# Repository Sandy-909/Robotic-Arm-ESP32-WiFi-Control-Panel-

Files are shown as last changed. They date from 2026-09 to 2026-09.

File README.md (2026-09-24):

# Robotic-Arm-ESP32-WiFi-Control-Panel-
An open-source, 3D-printed robotic arm controlled wirelessly over WiFi from a browser-based control panel — no app install, no cables, no COM port required. Built from scratch: CAD → 3D printing → embedded firmware → custom web UI. Fully assembled, wired, and working.

ROBOTIC_ARM

Overview

This project is a 5-axis robotic arm (Base, Shoulder, Elbow, Wrist Pitch, Wrist Roll, plus a Gripper) driven by an ESP32 microcontroller. The ESP32 hosts its own WiFi access point and serves a full control panel directly from the board — open the arm's IP address in any browser, no separate files, no app, no COM port. Every joint is controlled with a slider, with live angle readout, smooth per-joint speed-ramped movement, saved pose sequences, playback, and export/import.

All mechanical parts are 3D printed. All code — firmware and control panel — is included in this repo.

Features
6-channel servo control (5 arm joints + gripper)
Self-hosted browser control panel — served directly from the ESP32, just open its IP address
Live slider control per joint with real-time angle display
Smooth, per-joint speed-ramped movement — each joint moves in small steps rather than snapping instantly, with independently tunable speed per joint (heavier MG995 joints vs. lighter SG90 joints move differently)
Save Position — capture the current pose
Play Movements — play back saved poses in sequence with adjustable delay
Stop Movement — halt playback mid-sequence
Export / Import Positions — save and reload movement sequences as .json files
Reset Positions — return all joints to a safe default pose
No app installation — runs in any modern browser

## Hardware / Bill of Materials

| Component | Qty | Notes |
|---|---:|---|
| ESP32 Dev Board (NodeMCU-32S) | 1 | 5V input via onboard 5V/VIN pin |
| MG995 Servo (Positional, 180°) | 3 | Base, Shoulder, and Elbow joints |
| SG90 Servo | 3 | Wrist Pitch, Wrist Roll, and Gripper |
| 5V Input Power Supply (3A+) | 1 | Use a power adapter of 5V 3A  |
| DC Barrel Jack | 1 | Center-positive (tip = +, sleeve = −) |
| 3D Printed Parts | — | See `/cad` folder for STL and source files |
| M3 Screws & nuts | as required  | See CAD assembly  |
| Jumper Wires | — | Used for signal and power distribution |
⚠️ Important: Make sure any MG995 you buy is listed as 180° positional, not "continuous rotation" or "for robot wheels" — these look identical but behave completely differently. See Lessons Learned below.

### Wiring

circuit_image

## General Wiring Notes

- **Servo Signal:** Connect each servo's signal wire to a dedicated GPIO pin on the ESP32. See `SERVO_PINS[]` in the firmware and update the pin assignments to match your actual wiring.

- **Servo Power:** All servo V+ connections must come directly from the external buck converter's **5V rail**. Do **not** power the servos from the ESP32's onboard regulator.

- **ESP32 Power:** For untethered operation, power the ESP32 from the **same 5V/GND rail** as the servos through the board's **5V/VIN and GND pins**. Do not rely on USB power during normal operation.

- **Common Ground:** This is critical. Connect:
  - ESP32 GND
  - Power adapter GND
  - All servo GND wires
  
  These must share a common ground. Without a common reference, the PWM signals can become unstable and cause erratic or uncontrolled servo movement.

- **DC Barrel Jack:** Before soldering, use a multimeter in continuity mode to verify:
  - Tip = Positive (+)
  - Sleeve = Negative (−)
  
  Do not assume the pin arrangement. Some barrel jacks have a third **switch/detect pin** that can look like a power connection.

- **Perfboard / Prototyping Board:** Carefully inspect every solder joint along the power path. A cold or weak solder joint may show the correct voltage with a multimeter but still cause voltage drops during sudden current bursts, especially when the ESP32's Wi-Fi starts broadcasting.

## Software Setup

### Firmware (ESP32)

The firmware is located in the `/firmware` folder:

`robotic_arm_wifi_control_panel.ino`

This single file contains both the **Wi-Fi server** and the complete **web-based control panel** for the robotic arm.

### Requirements

- [Arduino IDE](https://www.arduino.cc/en/software) with **ESP32 board support** installed.
- **ESP32Servo** library by **Kevin Harrington**.
  - Install it through the Arduino IDE **Library Manager**.

## Setup & Upload

**Steps:**
1. Open `robotic_arm_wifi_control_panel.ino` in the **Arduino IDE**.
2. Update `SERVO_PINS[]` and `JOINT_NAMES[]` to match your actual wiring.
3. Tune the movement speed for each joint if required:
   - `STEP_SIZE[]` — degrees moved per step.
   - `STEP_INTERVAL_MS[]` — delay in milliseconds between steps.
   - Use one value for each joint.
   - Heavier **MG995** joints generally work better with smaller/slower steps, while lighter **SG90** joints can use faster movement.
4. *(Optional)* Change `WIFI_SSID` and `WIFI_PASSWORD` if required.
5. Connect the ESP32 and **upload the firmware**.
6. Open the **Serial Monitor** at `115200` baud.
7. Check the Serial Monitor for the arm's IP address. The default access point address is:
   ```text
   192.168.4.1

### Control Panel

No separate file or installation is required. The **ESP32 hosts and serves the control panel directly**.

**Steps:**

1. Power on the robotic arm.
2. On your phone or laptop, connect to the **ESP32 Wi-Fi network**. The SSID is shown in the Serial Monitor.
3. Open a web browser and enter the arm's IP address, for example:
   ```text
   http://192.168.4.1

### Contributing

Issues and pull requests are welcome. If you build this arm yourself, feel free to open an issue with photos — always good to see other builds.

### License

This project is licensed under the MIT License — free to use, modify, and distribute.

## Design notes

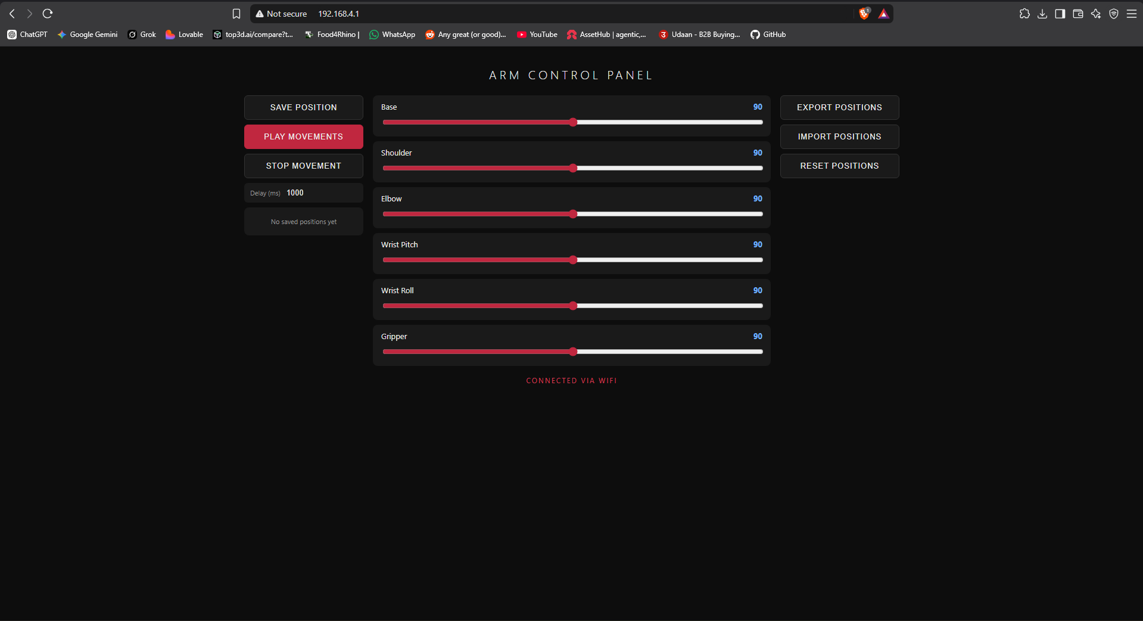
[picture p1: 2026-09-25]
firmware/GUI_PREVIEW.png

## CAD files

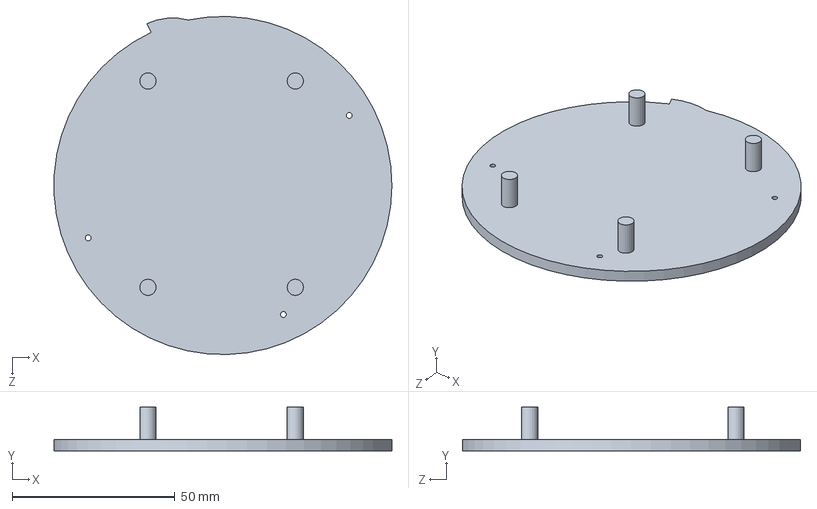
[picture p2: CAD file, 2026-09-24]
CAD/base_bottom cap.SLDPRT
103.9 x 13.5 x 104.0 mm

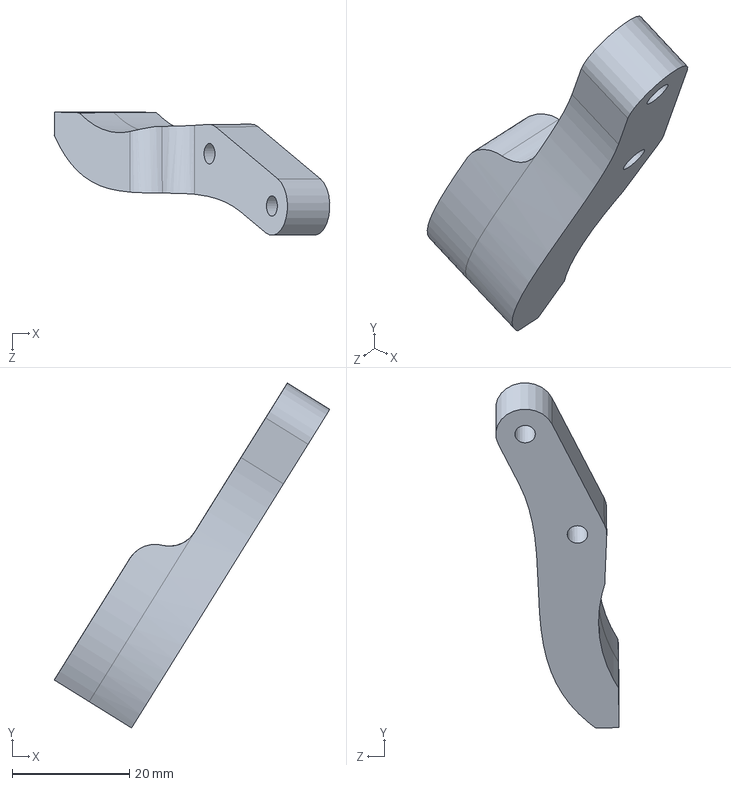
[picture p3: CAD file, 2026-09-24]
CAD/claw_hand_2.SLDPRT
46.9 x 58.8 x 21.0 mm

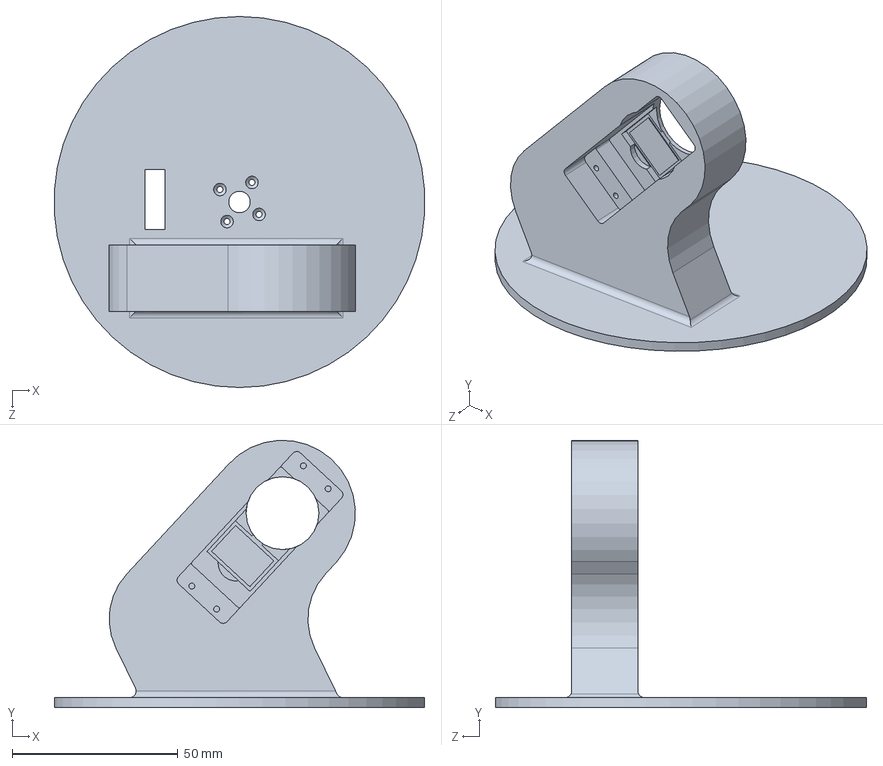
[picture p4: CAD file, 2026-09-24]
CAD/Link_1.SLDPRT
111.8 x 80.7 x 112.0 mm

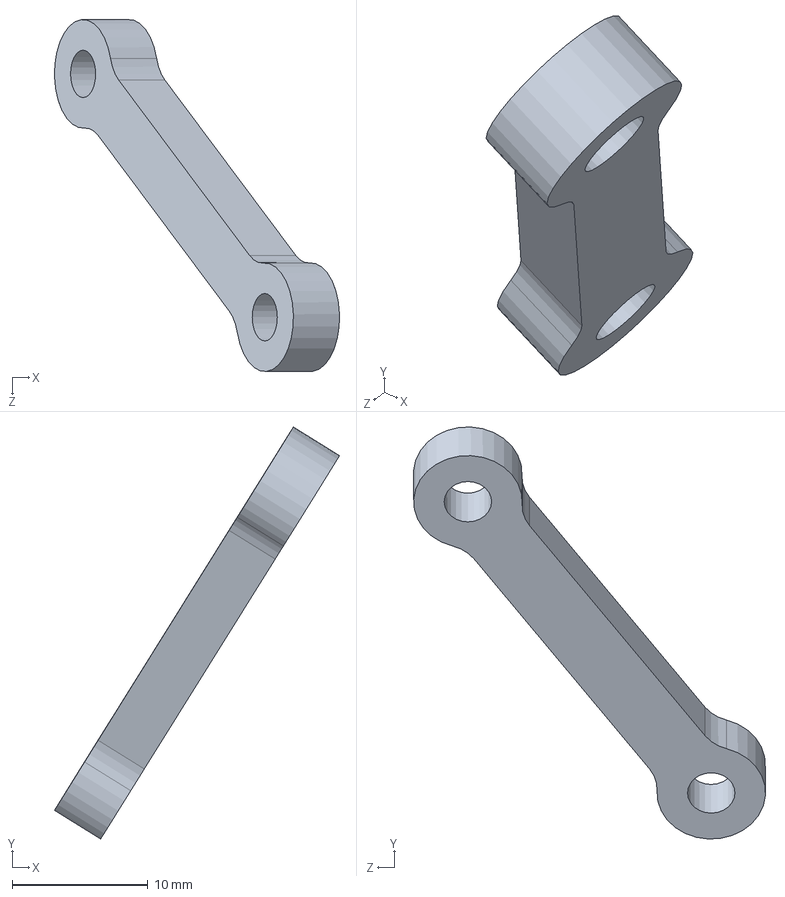
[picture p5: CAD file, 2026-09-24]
CAD/gear_link.SLDPRT
21.0 x 30.4 x 25.9 mm

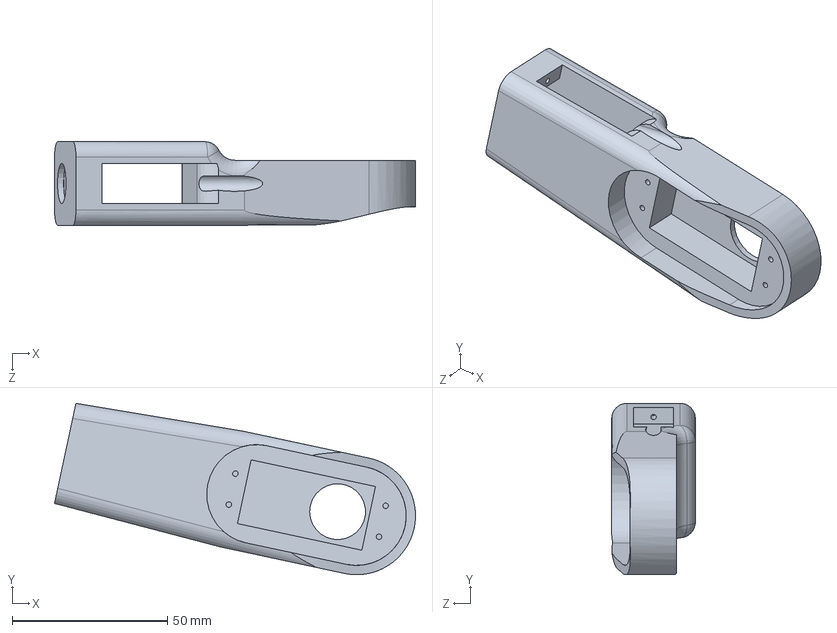
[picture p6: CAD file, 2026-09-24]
CAD/link_fix2.SLDPRT
116.3 x 55.2 x 27.0 mm

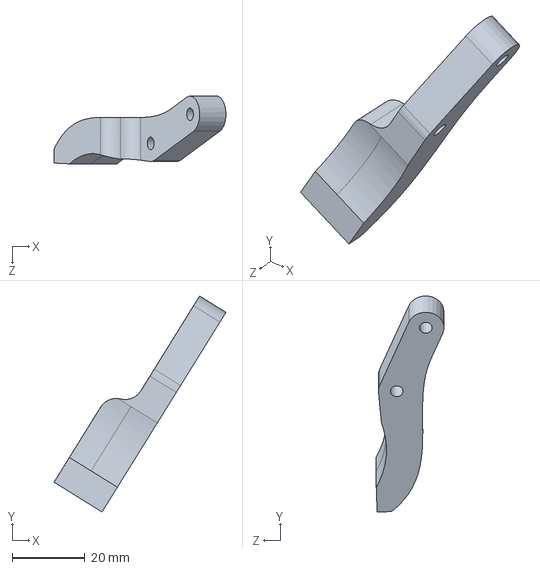
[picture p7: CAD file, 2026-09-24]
CAD/claw_hand.SLDPRT
47.2 x 59.3 x 18.6 mm

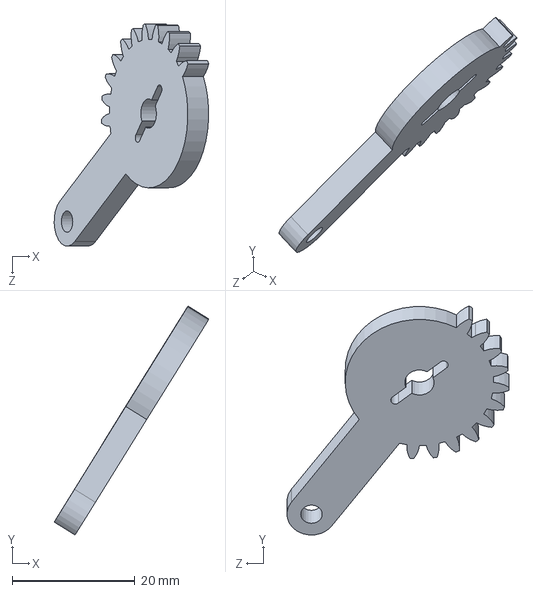
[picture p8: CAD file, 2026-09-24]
CAD/claw_gear2new.SLDPRT
25.2 x 37.3 x 36.2 mm

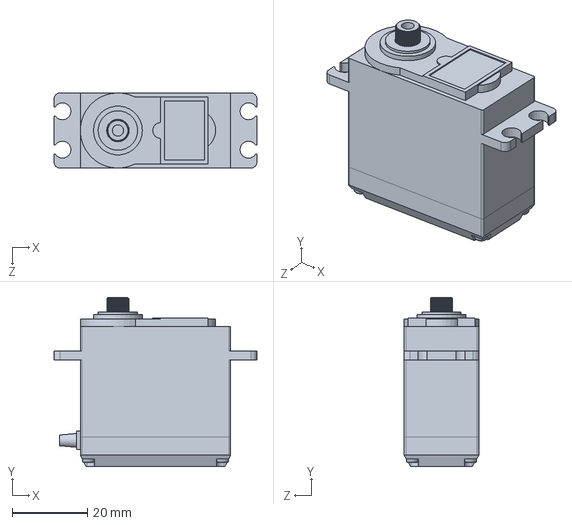
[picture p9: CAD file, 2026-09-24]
CAD/MG995.o11k.SLDPRT
54.0 x 45.0 x 20.0 mm

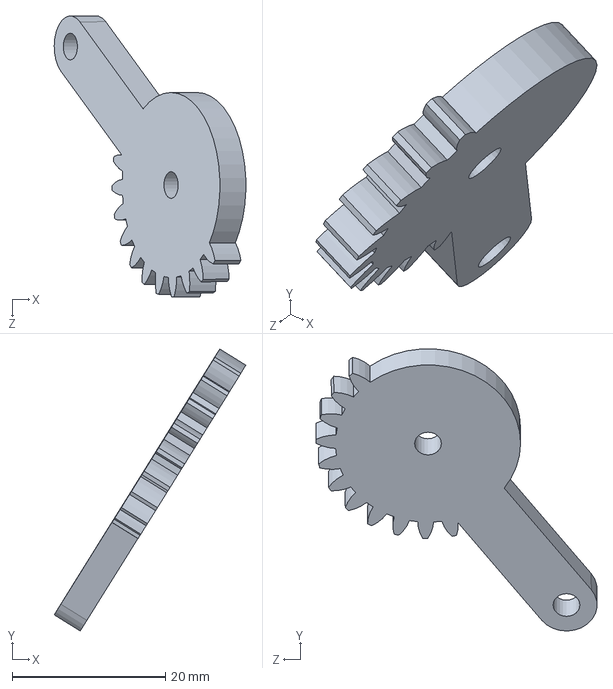
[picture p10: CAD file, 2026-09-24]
CAD/claw_gea1.SLDPRT
25.0 x 36.8 x 36.7 mm

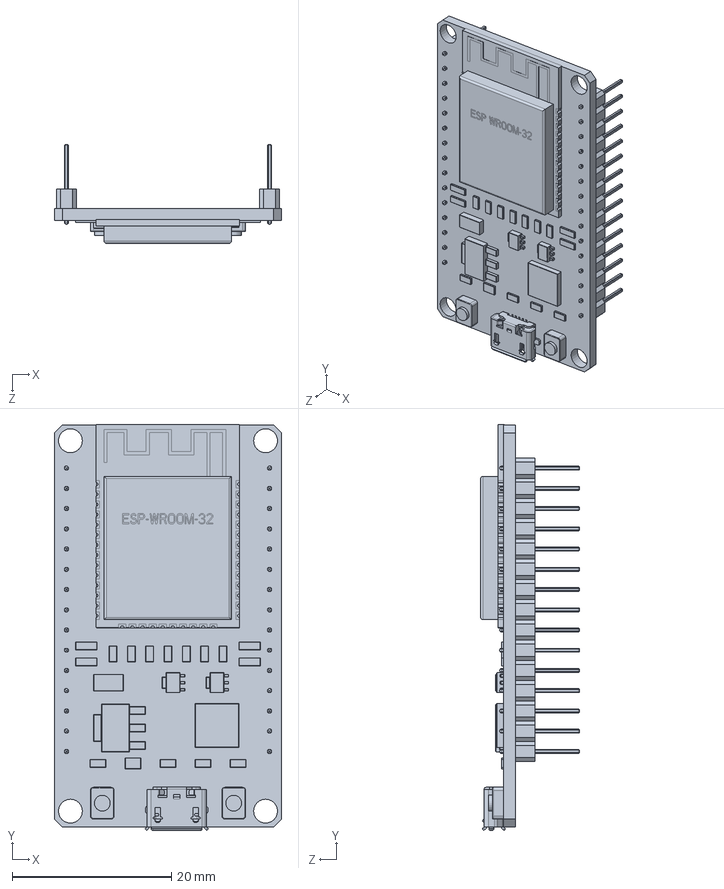
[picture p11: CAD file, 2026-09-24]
CAD/ESP-32.SLDPRT
28.5 x 51.0 x 12.4 mm

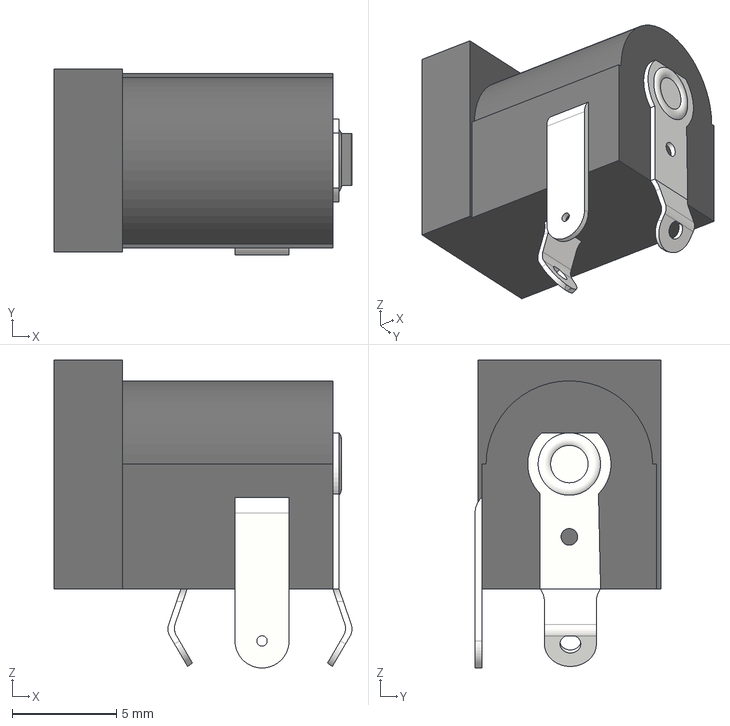
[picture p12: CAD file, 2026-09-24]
CAD/dc jack with legs.step
14.3 x 8.93 x 14.8 mm

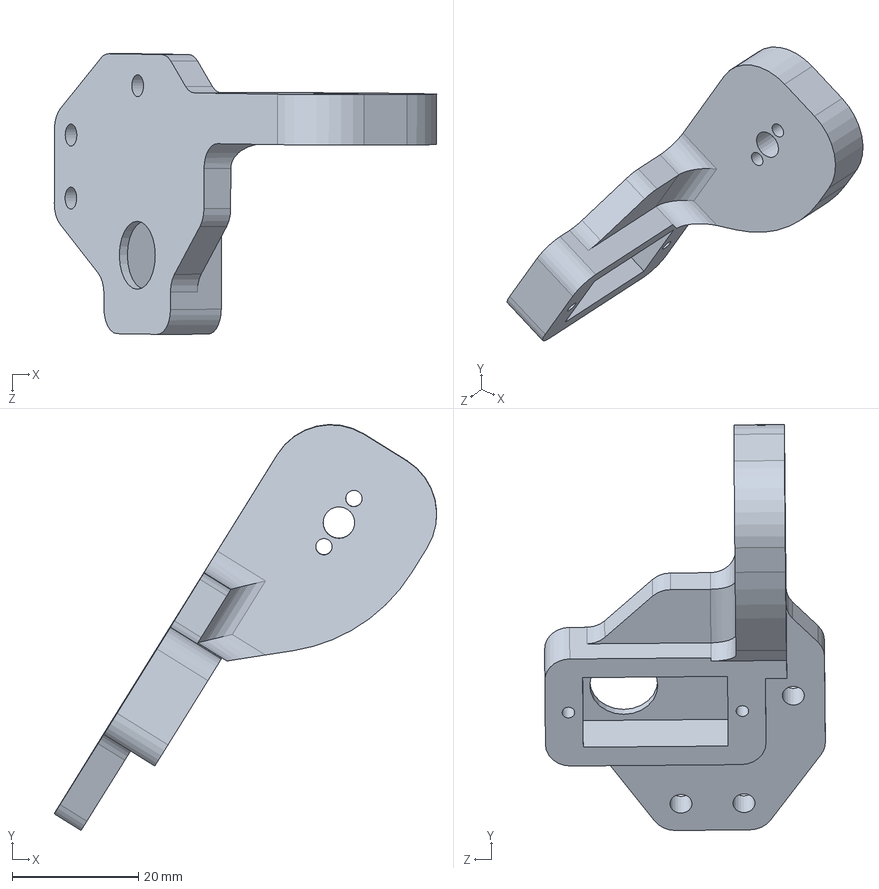
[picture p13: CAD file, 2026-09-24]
CAD/claw_1.SLDPRT
60.7 x 64.4 x 44.5 mm

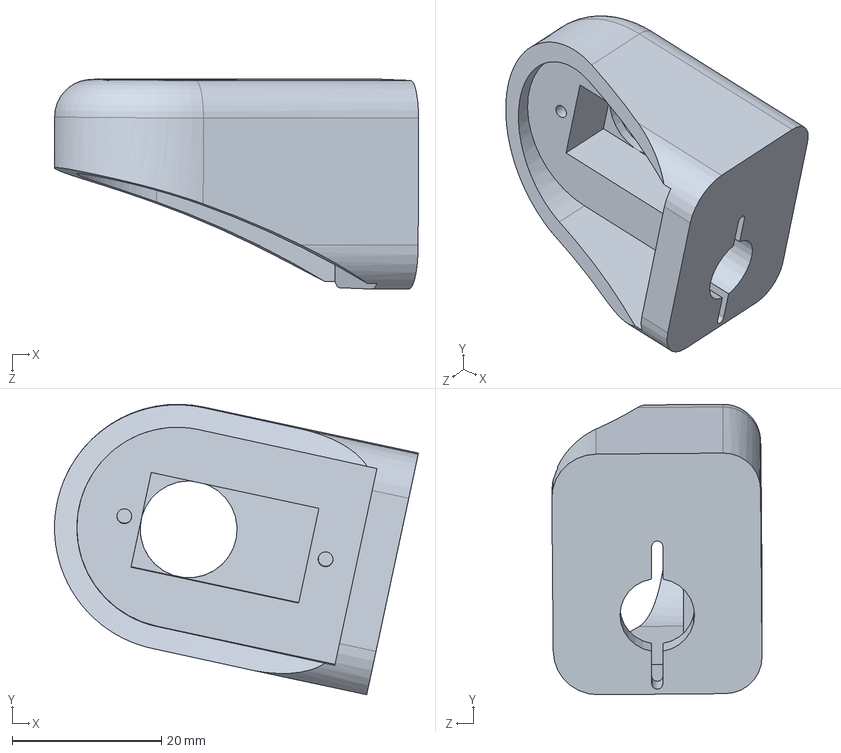
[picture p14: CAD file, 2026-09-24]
CAD/link_3.SLDPRT
48.8 x 39.0 x 28.2 mm

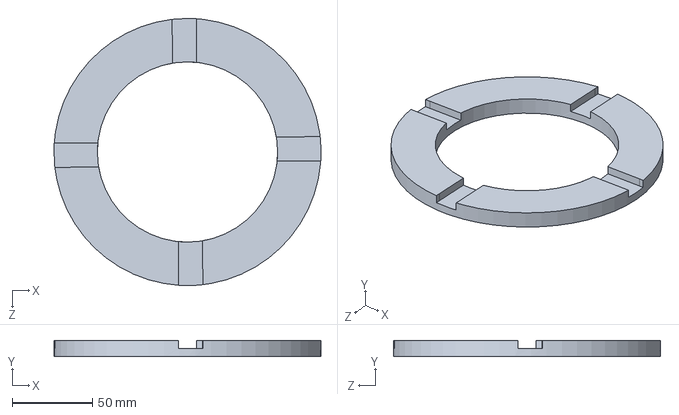
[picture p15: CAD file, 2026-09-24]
CAD/base_support.SLDPRT
165.9 x 10.0 x 166.0 mm

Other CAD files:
CAD/Assem1.SLDASM
CAD/MG995.step
CAD/link_2_new.SLDPRT
CAD/servo90s.SLDPRT
CAD/MG955 horn.SLDPRT
CAD/MG995.SLDASM
CAD/MG995.SLDPRT
CAD/Power jack.SLDPRT
CAD/base.SLDPRT

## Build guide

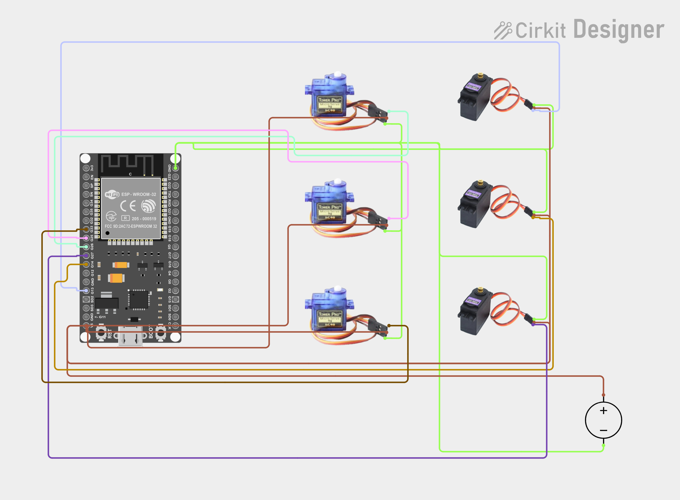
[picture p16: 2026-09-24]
wiring diagram/circuit_image.png

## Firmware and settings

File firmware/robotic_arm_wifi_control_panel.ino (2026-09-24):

/*
  6-Axis Robotic Arm - WiFi Web Control Panel - ESP32
  -------------------------------------------------------------------------
  ESP32 hosts its OWN WiFi network (Access Point mode). Connect your
  phone/laptop to that network, open the IP in a browser, and you get
  a full control panel: sliders, Save Position, Play Movements, Stop,
  Export/Import Positions (as a file), and Reset -- all running purely
  over WiFi, no USB/serial connection needed once it's powered on.

  WIRING:
    Update SERVO_PINS[] below to match your actual joint -> GPIO wiring.
    Label each joint in JOINT_NAMES[] to match your arm (Base, Shoulder, etc).
    All servos need a separate 5-6V supply (2A+ per servo) with GND
    common to the ESP32.

  SETUP:
    1. Install "ESP32Servo" library (Kevin Harrington) via Library Manager.
    2. Change WIFI_SSID / WIFI_PASSWORD below if you want.
    3. Upload, open Serial Monitor at 115200 to see the IP address.
    4. On your phone/laptop, join the WiFi network shown, then open that
       IP in any browser (e.g. http://192.168.4.1).
*/

#include <WiFi.h>
#include <WebServer.h>
#include <ESP32Servo.h>

// ---------- CONFIG: EDIT THESE FOR YOUR ARM ----------
const int SERVO_PINS[6]     = {13, 14, 27, 26, 25, 33};
const char* JOINT_NAMES[6]  = {"Base", "Shoulder", "Elbow", "Wrist Pitch", "Wrist Roll", "Gripper"};
const int DEFAULT_ANGLE[6]  = {90, 90, 90, 90, 90, 90};

const char* WIFI_SSID     = "RoboticArm";
const char* WIFI_PASSWORD = "arm12345";   // must be 8+ characters

// ---------- SPEED CONTROL (per joint) ----------
// Lower STEP_SIZE and/or higher STEP_INTERVAL_MS = slower, smoother movement.
// Higher STEP_SIZE and/or lower STEP_INTERVAL_MS = faster movement.
// Set one value per joint, in the same order as SERVO_PINS/JOINT_NAMES above.
// Example below: Base/Shoulder/Elbow are MG995 (slower, more torque),
// Wrist Pitch/Wrist Roll/Gripper are SG90 (faster, confirmed working at 2 steps / 30ms).
const int STEP_SIZE[6]         = {1,  1,  1,  2,  2,  2};   // degrees moved per step
const int STEP_INTERVAL_MS[6]  = {15, 15, 15, 30, 30, 30};  // milliseconds between steps
// ------------------------------------------------------

Servo joints[6];
int currentAngle[6];   // angle the servo is actually at right now
int targetAngle[6];    // angle we're ramping toward
unsigned long lastStepTime[6];  // tracked per servo since speeds now differ
WebServer server(80);

void handleRoot() {
  String html = "<!DOCTYPE html><html><head><meta charset='utf-8'>";
  html += "<meta name='viewport' content='width=device-width, initial-scale=1'>";
  html += "<title>Arm Control Panel</title><style>";
  html += ":root{--bg:#0d0d0d;--panel:#1a1a1a;--accent:#c0273f;--accent-hover:#d63a53;--text:#eee;--muted:#999;}";
  html += "*{box-sizing:border-box;}";
  html += "body{background:var(--bg);color:var(--text);font-family:'Segoe UI',Arial,sans-serif;margin:0;padding:20px;}";
  html += "h1{text-align:center;font-weight:300;letter-spacing:5px;font-size:20px;margin-bottom:22px;text-transform:uppercase;}";
  html += ".layout{display:flex;gap:16px;max-width:1100px;margin:0 auto;flex-wrap:wrap;}";
  html += ".col{display:flex;flex-direction:column;gap:8px;}";
  html += ".col-side{width:200px;}";
  html += ".col-main{flex:1;min-width:280px;}";
  html += "button,select{background:var(--panel);color:var(--text);border:1px solid #333;border-radius:6px;padding:12px 10px;font-size:13px;letter-spacing:1px;cursor:pointer;text-transform:uppercase;width:100%;}";
  html += "button:hover{background:#262626;}";
  html += "button:disabled{opacity:0.4;cursor:not-allowed;}";
  html += ".primary{background:var(--accent);border-color:var(--accent);}";
  html += ".primary:hover{background:var(--accent-hover);}";
  html += ".primary.playing{background:var(--accent-hover);}";
  html += ".joint{background:var(--panel);border-radius:8px;padding:10px 14px;}";
  html += ".joint-label{display:flex;justify-content:space-between;font-size:13px;margin-bottom:6px;}";
  html += ".joint-label .val{color:#6fb3ff;font-weight:bold;}";
  html += "input[type=range]{width:100%;accent-color:var(--accent);height:20px;}";
  html += ".delay-box{display:flex;align-items:center;background:var(--panel);border-radius:6px;padding:8px 10px;gap:8px;}";
  html += ".delay-box input{background:transparent;border:none;color:var(--text);width:100%;font-size:13px;}";
  html += ".delay-box label{font-size:11px;color:var(--muted);white-space:nowrap;}";
  html += ".status{text-align:center;margin-top:16px;font-size:12px;letter-spacing:2px;color:var(--muted);text-transform:uppercase;}";
  html += ".status.active{color:var(--accent-hover);}";
  html += ".saved-list{background:var(--panel);border-radius:8px;padding:8px 12px;max-height:150px;overflow-y:auto;font-size:12px;}";
  html += ".pose-row{display:flex;justify-content:space-between;align-items:center;padding:5px 0;border-bottom:1px solid #262626;}";
  html += ".pose-row:last-child{border-bottom:none;}";
  html += ".pose-row button{width:auto;padding:3px 7px;font-size:10px;}";
  html += ".empty-note{color:var(--muted);font-size:11px;text-align:center;padding:8px 0;}";
  html += "#importFile{display:none;}";
  html += "</style></head><body>";
  html += "<h1>Arm Control Panel</h1><div class='layout'>";

  // Left column
  html += "<div class='col col-side'>";
  html += "<button id='saveBtn'>Save Position</button>";
  html += "<button id='playBtn' class='primary'>Play Movements</button>";
  html += "<button id='stopBtn'>Stop Movement</button>";
  html += "<div class='delay-box'><label>Delay (ms)</label><input type='number' id='delayInput' value='1000' min='50' step='50'></div>";
  html += "<div class='saved-list' id='savedList'><div class='empty-note'>No saved positions yet</div></div>";
  html += "</div>";

  // Middle column: sliders
  html += "<div class='col col-main' id='jointContainer'>";
  for (int i = 0; i < 6; i++) {
    html += "<div class='joint'>";
    html += "<div class='joint-label'><span>" + String(JOINT_NAMES[i]) + "</span><span class='val' id='v" + i + "'>" + String(currentAngle[i]) + "</span></div>";
    html += "<input type='range' min='0' max='180' value='" + String(currentAngle[i]) + "' id='s" + i + "' oninput='onSlide(" + String(i) + ",this.value)'>";
    html += "</div>";
  }
  html += "</div>";

  // Right column
  html += "<div class='col col-side'>";
  html += "<button id='exportBtn'>Export Positions</button>";
  html += "<button id='importBtn'>Import Positions</button>";
  html += "<input type='file' id='importFile' accept='application/json'>";
  html += "<button id='resetBtn'>Reset Positions</button>";
  html += "</div>";

  html += "</div><div class='status active' id='statusLine'>Connected via WiFi</div>";

  // JS
  html += "<script>";
  html += "let angles=[" ;
  for (int i = 0; i < 6; i++) { html += String(currentAngle[i]); if (i < 5) html += ","; }
  html += "];";
  html += "let savedPoses=[];let playing=false;let stopRequested=false;";
  html += "const playBtn=document.getElementById('playBtn');const statusLine=document.getElementById('statusLine');const savedList=document.getElementById('savedList');";

  html += "function setStatus(t,a){statusLine.innerText=t;statusLine.classList.toggle('active',!!a);}";

  html += "function onSlide(i,v){angles[i]=parseInt(v);document.getElementById('v'+i).innerText=v;sendAngles();}";

  html += "function updateSliders(){angles.forEach((a,i)=>{document.getElementById('s'+i).value=a;document.getElementById('v'+i).innerText=a;});}";

  html += "async function sendAngles(){";
  html += "let url='/moveAll?';";
  html += "angles.forEach((a,i)=>{url+='a'+i+'='+a+'&';});";
  html += "try{await fetch(url);}catch(e){setStatus('Send failed -- check WiFi connection');}";
  html += "}";

  html += "function renderSavedList(){";
  html += "if(savedPoses.length===0){savedList.innerHTML='<div class=\"empty-note\">No saved positions yet</div>';return;}";
  html += "savedList.innerHTML='';";
  html += "savedPoses.forEach((pose,idx)=>{";
  html += "const row=document.createElement('div');row.className='pose-row';";
  html += "row.innerHTML='<span>Pose '+(idx+1)+': '+pose.join(', ')+'</span>';";
  html += "const delBtn=document.createElement('button');delBtn.innerText='X';";
  html += "delBtn.onclick=()=>{savedPoses.splice(idx,1);renderSavedList();};";
  html += "row.appendChild(delBtn);savedList.appendChild(row);";
  html += "});}";

  html += "function sleep(ms){return new Promise(r=>setTimeout(r,ms));}";

  html += "document.getElementById('saveBtn').addEventListener('click',()=>{savedPoses.push([...angles]);renderSavedList();});";

  html += "document.getElementById('playBtn').addEventListener('click',async()=>{";
  html += "if(playing)return;";
  html += "if(savedPoses.length===0){setStatus('No saved positions to play');return;}";
  html += "playing=true;stopRequested=false;playBtn.classList.add('playing');";
  html += "const delayMs=parseInt(document.getElementById('delayInput').value)||1000;";
  html += "for(let i=0;i<savedPoses.length;i++){";
  html += "if(stopRequested)break;";
  html += "angles=[...savedPoses[i]];updateSliders();await sendAngles();";
  html += "setStatus('Playing movement '+(i+1)+' of '+savedPoses.length,true);";
  html += "await sleep(delayMs);}";
  html += "playing=false;playBtn.classList.remove('playing');";
  html += "setStatus(stopRequested?'Stopped':'Playback finished',true);";
  html += "});";

  html += "document.getElementById('stopBtn').addEventListener('click',()=>{stopRequested=true;setStatus('Stopping...');});";

  html += "document.getElementById('exportBtn').addEventListener('click',()=>{";
  html += "const blob=new Blob([JSON.stringify(savedPoses,null,2)],{type:'application/json'});";
  html += "const url=URL.createObjectURL(blob);const a=document.createElement('a');";
  html += "a.href=url;a.download='arm_positions.json';a.click();URL.revokeObjectURL(url);";
  html += "});";

  html += "document.getElementById('importBtn').addEventListener('click',()=>{document.getElementById('importFile').click();});";

  html += "document.getElementById('importFile').addEventListener('change',(e)=>{";
  html += "const file=e.target.files[0];if(!file)return;";
  html += "const r=new FileReader();";
  html += "r.onload=(evt)=>{try{const data=JSON.parse(evt.target.result);if(Array.isArray(data)){savedPoses=data;renderSavedList();setStatus('Positions imported',true);}}catch(err){setStatus('Invalid file');}};";
  html += "r.readAsText(file);";
  html += "});";

  html += "document.getElementById('resetBtn').addEventListener('click',()=>{";
  html += "angles=[" ;
  for (int i = 0; i < 6; i++) { html += String(DEFAULT_ANGLE[i]); if (i < 5) html += ","; }
  html += "];updateSliders();sendAngles();";
  html += "});";

  html += "</script></body></html>";

  server.send(200, "text/html", html);
}

void handleMoveAll() {
  for (int i = 0; i < 6; i++) {
    String param = "a" + String(i);
    if (server.hasArg(param)) {
      int angle = constrain(server.arg(param).toInt(), 0, 180);
      targetAngle[i] = angle;   // servo will ramp toward this in loop(), not jump instantly
    }
  }
  server.send(200, "text/plain", "OK");
}

// Moves each servo one small step closer to its target, at a fixed interval.
// This runs continuously in loop() so movement is smooth and non-blocking --
// the web page stays responsive while servos are still ramping.
void updateServoPositions() {
  unsigned long now = millis();
  for (int i = 0; i < 6; i++) {
    if (now - lastStepTime[i] < STEP_INTERVAL_MS[i]) continue;
    if (currentAngle[i] == targetAngle[i]) continue;

    lastStepTime[i] = now;
    if (currentAngle[i] < targetAngle[i]) {
      currentAngle[i] = min(currentAngle[i] + STEP_SIZE[i], targetAngle[i]);
    } else {
      currentAngle[i] = max(currentAngle[i] - STEP_SIZE[i], targetAngle[i]);
    }
    joints[i].write(currentAngle[i]);
  }
}

void setup() {
  Serial.begin(115200);
  delay(500);

  ESP32PWM::allocateTimer(0);
  ESP32PWM::allocateTimer(1);
  ESP32PWM::allocateTimer(2);
  ESP32PWM::allocateTimer(3);

  for (int i = 0; i < 6; i++) {
    joints[i].setPeriodHertz(50);
    joints[i].attach(SERVO_PINS[i], 500, 2400);
    currentAngle[i] = DEFAULT_ANGLE[i];
    targetAngle[i] = DEFAULT_ANGLE[i];
    joints[i].write(currentAngle[i]);
  }

  WiFi.softAP(WIFI_SSID, WIFI_PASSWORD);
  IPAddress ip = WiFi.softAPIP();

  Serial.println("=======================================");
  Serial.println(" Robotic Arm Web Control Panel Ready");
  Serial.println("=======================================");
  Serial.print("Connect to WiFi: ");
  Serial.println(WIFI_SSID);
  Serial.print("Password: ");
  Serial.println(WIFI_PASSWORD);
  Serial.print("Then open in browser: http://");
  Serial.println(ip);

  server.on("/", handleRoot);
  server.on("/moveAll", handleMoveAll);
  server.begin();
}

void loop() {
  server.handleClient();
  updateServoPositions();
}
